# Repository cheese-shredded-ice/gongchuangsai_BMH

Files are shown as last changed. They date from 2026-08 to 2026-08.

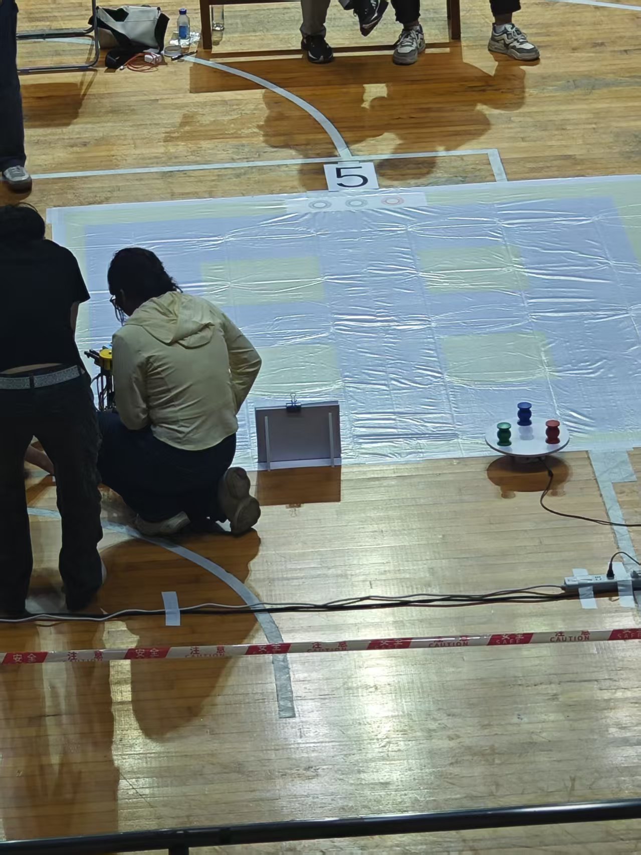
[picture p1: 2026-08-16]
图片/现场地图.jpg

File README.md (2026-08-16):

    

# 2026 年广东省工创大赛 · 智能物流搬运机器人 资料库

本仓库收录「智能物流搬运」赛项（MBH 项目）的完整参赛资料，涵盖 **结构设计、电控程序、视觉程序、任务命题文档、现场比赛经验** 五大板块。

> 项目主控：STM32F407（底层运动控制）＋ 地瓜派RDK X5（视觉识别），麦轮底盘 + 舵机机械臂 + CAN 总线电机。

> 本工程基于 [gcs-gold-medal](https://github.com/yuanxiexie531-glitch/gcs-gold-medal) 开源项目。

---

## 一、仓库结构总览

```
gongchuangsai_BMH/
├── 结构件/                  # 机械结构原始设计文件（CATIA / SolidWorks）
├── 打印部件/                # 3D 打印件模型（STP / STEP / SLDPRT / 3mf）
├── 电控程序/                # STM32F407 嵌入式工程（初赛版 / 决赛版）
├── 视觉程序/                # RDK X5 视觉主程序
│   ├── gongchuang_vision.py         # 初赛
│   └── gongchuang_vision_final.py   # 决赛
├── 图片/                    # 现场照片、地图、流程、评分表等
├── 全流程说明.md            # 系统架构、通信协议、完整任务流程
├── 2026年广东省工创大赛-设计文档MBH.docx
├── 说明文档byph.docx
├── 打印件摆盘.3mf
└── Drawingmoban.CATDrawing
```

---

## 二、结构设计

### 2.1 结构件（原始设计文件）

位于 [`结构件/`](./结构件/)：

| 文件 | 说明 |
| --- | --- |
| `zhua.CATPart` | 机械夹爪三维模型 |
| `四爪夹爪环形.SLDPRT` | 四爪夹爪（环形） |
| `Drawingmoban.CATDrawing` | CATIA 工程图模板 |

### 2.2 打印部件（3D 打印模型）

位于 [`打印部件/`](./打印部件/)，共 100+ 个零件，按功能大致分为：

- **夹爪类**：`四爪夹爪 4mm`、`2mm勾爪`、`30mm圆勾爪`、`圆勾爪`、`齿轮20x1.25 左/右爪`、`手爪固定板`、`手爪舵机固定架`、`gudinggouzhua` 等
- **平台/置物类**：`置物盘2A垫高`、`置物盘3A`、`置物盘3AHIGH`、`配重平台`、`配重盒底板`、`平台垫块`、`平台垫块支撑`
- **固定/连接类**：`固定基准板3A 4mm`、`锁紧固定板3A 4mm`、`底板3A 4mm`、`底板连接件1/2/3`、`直线导轨转接板`、`升降台固定板/转接板` 等
- **传动类**：`圆柱齿轮20×2`、`齿条模数2x20 40齿`、`齿轮20x1.25 舵机法兰盘`、`锁紧固定板带圆弧齿`
- **摄像头/传感类**：`二维码摄像头固定板C`、`向下摄像头平台`、`向下摄像头平台ov5647 3A`、`摄像头平台`、`串口屏固定板`
- **电机类**：`35电机平台`、`42步进电机支架`、`平推电机固定板35电机`、`平推转线板3.1`
- **其他**：`红物块`（比赛物块模型）、`轮胎垫片`、`舵机固定小板` 等

> 打印摆盘见 [`打印件摆盘.3mf`](./打印件摆盘.3mf)。

---

## 三、电控程序

位于 [`电控程序/`](./电控程序/)，为 STM32F407（Keil MDK）工程，含 **初赛版** 与 **决赛版** 两个版本：

| 版本 | 路径 | 说明 |
| --- | --- | --- |
| 初赛版 | [`电控程序/BMH-初赛/`](./电控程序/BMH-初赛/) | 完整工程，含全部功能模块 |
| 决赛版 | [`电控程序/BMH-决赛/`](./电控程序/BMH-决赛/) | 决赛迭代版本 |

### 核心代码模块

| 模块 | 路径 | 功能 |
| --- | --- | --- |
| `USER` | `main.c` / `car.c` / `car.h` | 主程序、整车运动控制（麦轮、走线） |
| `USER` | `cmd_parser.c/h` | 命令解析 |
| `USER` | `exti.c/h` | 外部按键中断 |
| `Hardware` | `PWM.c/h`、`servo.c/h` | 舵机 PWM 控制 |
| `Hardware` | `pid.c/h` | PID 控制 |
| `Hardware` | `swith.c/h` | 限位开关 |
| `can_ZDT` | `Emm_V5`、`can`、`circle_pid`、`yyb_move`、`fifo`、`board` | CAN 总线电机控制、环形运动、搬运移动 |
| `imu` | `imu.c`、`wit_c_sdk.c`、`timer.c`、`REG.h` | WHT101 惯性测量单元（USART2） |
| `SYSTEM` | `Serial`、`usart`、`delay`、`sys` | 串口、延时、系统基础 |
| `OLED` / `LED` | `OLED.c`、`time_OLED.c`、`LED.c`、`light.c` | 显示与指示灯 |
| `lanya` | `hmi.c`、`usart5.c` | 蓝牙 / HMI 串口屏通信 |
| `ckp` | `uart6_ckp.c/h` | 串口屏 |
| `CORE` / `FWLIB` | CMSIS + STM32F4 标准外设库 | 内核与底层驱动 |

### 调试工具

- [`CMSIS-DAP/`](./电控程序/BMH-初赛/CMSIS-DAP/)：仿真器固件（X893 版 / 官方原版）、电路原理图、WIN7 驱动、DIY 教程。

---

## 四、视觉程序

视觉端跑在 **地瓜派RDK X5** 上。源码已收录：

| 版本 | 文件 | 说明 |
| ---- | --- | --- |
| 初赛 | [`视觉程序/gongchuang_vision.py`](./视觉程序/gongchuang_vision.py) | 二维码、转盘物块、色环、码垛 |
| 决赛 | [`视觉程序/gongchuang_vision_final.py`](./视觉程序/gongchuang_vision_final.py) | 初赛能力 + 固定物料区三工位 + 成品区 Code128 转盘 |

STM32 通过 UART 下发单字节任务码，RDK X5 完成识别后按同一帧格式回传坐标、颜色或任务码。颜色约定：`1` 红、`2` 绿、`3` 蓝。决赛成品区条码 `1/2/3` 是独立编号，不走颜色映射。

### 4.1 运行环境

| 项目 | 说明 |
| --- | --- |
| 板卡 | 地瓜派RDK X5 |
| 系统 | Ubuntu / Linux（V4L2） |
| 语言 | Python 3 |
| 依赖 | `opencv-python`、`numpy`、`pyserial`、`pyzbar` |
| 串口 | `/dev/ttyUSB0`，9600 8N1 |
| 下摄像头 | `/dev/video0`，扫任务二维码 |
| 上摄像头 | `/dev/video2`，物块、色环、码垛、物料区和成品区条码  |
| OpenCV | 打开优化，8 线程 |

定标时上摄像头按 MJPEG、30 FPS、双缓冲协商分辨率。物块/色环粗定标用 `640×480`，色环精细定标切到 `1920×1080`。决赛里 `/dev/video2` 由 `ensure_video2_camera()` 统一复用，避免重复打开。

板端启动：

```bash
python3 gongchuang_vision.py          # 初赛
python3 gongchuang_vision_final.py    # 决赛
```

程序起来后先发 `987654321`，表示视觉端就绪，然后循环等 STM32 指令。

### 4.2 通信协议

收发都是：

```
0xFF + 9 字节 ASCII + 0xFE
```

不足 9 字节的数据后面补 `0x00`。STM32 发单字符任务码，视觉端回 9 字节结果。常见回传：

| 内容 | 格式 | 含义 |
| --- | --- | --- |
| 任务码 | `132+3120` 一类 7 位码再补齐 | 二维码识别结果 |
| 物块/色环坐标 | `XXXXYYYYC` | X、Y 各 4 位，C 为颜色 |
| 转盘 / 物料 / 条码夹取顺序 | `ABC456789` | 三个工位相对位置 |
| 就绪 / 确认 | `987654321` | 上电就绪，或颜色/条码确认稳定 |
| 超时 / 失败 | `000000004` | 本次识别失败 |

更细的阶段约定见 [`全流程说明.md`](./全流程说明.md) 第三、四、五章。

### 4.3 STM32 任务码

| 指令 | 函数 | 作用 |
| --- | --- | --- |
| `1` | `run_erweima()` | 下摄像头扫 7 位任务码，连续 3 帧一致后回传 |
| `2` | `run_wukuaiyuanxin_1()` | 第一圈转盘，定第一个物块圆心和颜色 |
| `a` | `run_wukuaiyuanxin_1()` | 第二圈转盘，同样先定第一个物块 |
| `3` | `LOOP1()` | 第一圈转盘转起来后，算三个物块抓取顺序 |
| `4` | `LOOP2()` | 第二圈转盘，按任务码后三位再算一遍顺序 |
| `5` / `6` | `run_wukuaiyuanxin_xuanzequyu()` | 第一圈抓完第 1、2 个后，确认下一个物块到了 |
| `b` / `c` | `run_wukuaiyuanxin_xuanzequyu()` | 第二圈同样确认后两个物块 |
| `7` | `run_sehuanyuanxin2()` | 色环第一次粗定标，`640×480` |
| `8` | `run_sehuanyuanxin2_centered()` | 色环精细定标：半分辨率粗检 + 全分辨率局部精修 |
| `9` / `0` | `run_maduoyuanxin2()` | 码垛圆环定标 |
| `d` | `yunxing_tiaoxingma_dingbiao()` | **决赛** 成品区 Code128 首次定标，回 `XXXXYYYYC` |
| `e` | `yunxing_tiaoxingma_zhuanpan()` | **决赛** 等条码变化，判向后回三次夹取位置 |
| `f` / `g` | `yunxing_tiaoxingma_xuanzequyu()` | **决赛** 确认条码 `2`、`3` 已到夹取位 |
| `h` | `run_maduoyuanxin2()` | **决赛** 固定物料区定标 |
| `i` | `yunxing_sangeyuanxin_shibie_q123()` | **决赛** 识别 Q1/Q2/Q3，按当前轮任务码回夹取顺序 |
| `r` | `restart_program()` | 关串口，20 秒后重启视觉程序 |
| `end` | 退出主循环 | 本轮任务结束 |

初赛里 `d` 只回 `000000000`，直线纠偏没启用。决赛把 `d/e/f/g` 改成成品区条码流程，`h/i` 是固定物料区。

### 4.4 识别思路

- **二维码**：`/dev/video0` 转灰度，`pyzbar` 解码，连续 3 帧相同才认。
- **转盘物块**：Hough 圆 + HSV 红绿蓝面积。红用两段色相。位置和颜色都稳定后才回传。
- **三个物块颜色**：先看左下 A1、右下 A2，A3 用排除法补出来，再对照任务码算抓取顺序。
- **色环粗定标**：全图找圆，限制在画面中部有效区，颜色和位置累计稳定后发送。
- **色环精定标**：先在中心合法区内半分辨率粗找，再切回 `1920×1080` 局部精修圆心。
- **码垛 / 物料区定标**：圆环更小，半径大约 `20~27`。
- **固定物料区（决赛 `h/i`）**：Q1/Q2/Q3 三个固定工位只看颜色。任务 `i` 第一轮对照二维码 `A1/A2/A3`，第二轮对照 `A4/A5/A6`，回 `ABC456789`。
- **成品区 Code128（决赛 `d/e/f/g`）**：`pyzbar` 只解 Code128。`d` 记下当前条码和圆心；`e` 等条码变化后，按左下/右下/上方三个位置判向，目标顺序固定为 `1→2→3`；`f/g` 再确认后两个条码到了。

上摄像头在 RDK X5 上通常只能占一路。决赛用 `ensure_video2_camera()` 共用 `/dev/video2`，避免重复打开失败。

### 4.5 依赖安装

```bash
sudo apt update
sudo apt install -y python3-opencv python3-numpy python3-serial libzbar0
pip3 install pyzbar
```

串口和摄像头权限不够时：

```bash
sudo usermod -aG dialout,video $USER
```

重新登录后再跑。

---

## 五、任务命题文档

| 文件 | 说明 |
| --- | --- |
| [`2026年广东省工创大赛-设计文档MBH.docx`](./2026年广东省工创大赛-设计文档MBH.docx) | 赛项设计文档 / 命题相关材料 |
| [`说明文档byph.docx`](./说明文档byph.docx) | 完整任务流程、通信协议、成功/失败处理汇总 |
| [`全流程说明.md`](./全流程说明.md) | 项目说明文档 |

---

## 六、现场比赛经验

现场照片与资料位于 [`图片/`](./图片/)：

| 文件 | 内容 |
| --- | --- |
| `现场.jpg` | 比赛现场全景 |
| `现场地图.jpg` | 场地地图 |
| `现场流程.jpg` | 比赛流程 |
| `评分表.jpg` | 评分标准 |
| `acsll码表.png` | ASCII 码表（调试参考） |
| `现场葫芦五兄弟.jpg`、`罪恶二维码板.jpg`、`自断一臂.jpg` | 现场记录（含场地道具、二维码板等） |

比赛关键经验与踩坑点集中在 [`全流程说明.md`](./全流程说明.md)：

- **系统架构**：STM32 管 CAN、PID、麦轮和舵机；RDK X5 管 OpenCV / pyzbar 识别，两边走 UART
- **通信协议**：`0xFF + 9 字节 ASCII + 0xFE`，单字节命令触发视觉任务
- **完整任务流程**：扫码取任务 → 圆台取料 → 穿越 1700mm 通道 → 色环放置/取回 → 返回，共 9 个阶段
- **失败处理**：视觉未识别、颜色不匹配、超时等场景的应对策略
- **注意事项**：`jixie_reset()` 末尾 `while(1){}` 会导致第二轮不运行等已知问题

---

## 七、快速导航

| 想了解什么 | 去看 |
| --- | --- |
| 系统架构与通信协议 | [`全流程说明.md`](./全流程说明.md) 第一、三章 |
| 完整任务流程（9 阶段） | [`全流程说明.md`](./全流程说明.md) 第四、六章 |
| 初赛视觉主程序 | [`视觉程序/gongchuang_vision.py`](./视觉程序/gongchuang_vision.py) |
| 决赛视觉主程序 | [`视觉程序/gongchuang_vision_final.py`](./视觉程序/gongchuang_vision_final.py) |
| 底层运动控制代码 | [`电控程序/BMH-决赛/USER/`](./电控程序/BMH-决赛/USER/) |
| 机械结构三维模型 | [`结构件/`](./结构件/) 与 [`打印部件/`](./打印部件/) |
| 现场照片与评分标准 | [`图片/`](./图片/) |

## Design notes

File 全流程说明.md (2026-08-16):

# 智能物流机器人 全流程说明文档

---

## 一、系统架构

```
┌──────────────┐       UART1 9600bps        ┌──────────────┐
│   STM32F407  │◄──────────────────────────►│   RDK X5     │
│   (底层控制)  │   0xFF + 9字节ASCII + 0xFE  │   (视觉识别)  │
│              │   单字节命令                  │              │
│  ● CAN总线   │                              │  ● OpenCV    │
│  ● PID控制   │                              │  ● pyzbar    │
│  ● 麦轮运动  │                              │  ● 串口通信   │
│  ● 舵机控制  │                              │              │
└──────────────┘                              └──────────────┘
```

**数据帧格式：**  
- STM32 → RDK X5：1字节 ASCII 命令  
- RDK X5 → STM32：`0xFF` + 9字节 ASCII 数据 + `0xFE`

视觉主程序：[`视觉程序/gongchuang_vision.py`](./视觉程序/gongchuang_vision.py)  
下摄像头 `/dev/video0` 扫码，上摄像头 `/dev/video2` 做物块 / 色环 / 码垛定标，串口 `/dev/ttyUSB0`。

---

## 二、当前版本说明

| 文件 | 说明 |
|---|---|
| `电控程序/BMH-初赛` / `电控程序/BMH-决赛` | STM32 工程。无视觉版任务码可硬编码，跳过视觉通信，只跑一轮 |
| [`视觉程序/gongchuang_vision.py`](./视觉程序/gongchuang_vision.py) | RDK X5 视觉主程序，含完整通信协议和任务分发 |

> 被注释掉的 `wait_send_shumeipai()` 等代码，在下方表格中用 **[注释]** 标记，表示完整视觉版才会执行。

---

## 三、完整通信协议表

| STM32 发送 | 触发时机 | RDK X5 收到后执行 | RDK X5 发回数据 | STM32 收到后操作 |
|:---:|---|---|---|---|
| `0x31` | **[注释]** 扫码阶段 | `run_erweima()` 打开 `/dev/video0`，pyzbar 识别二维码，连续 3 帧相同确认 | `"123+3210"` → 7 位任务码再补齐 | 解析 task[0..5] |
| `0x32` | **[注释]** 圆台物块定标 | `run_wukuaiyuanxin_1()` HoughCircle + HSV，位置稳定 30 帧 + 颜色置信度≥70% | `"095505191"` → XXXX YYYY C R | 解析像素坐标+颜色，`C_1=颜色` |
| `0x33` | **[注释]** 转盘排序(第一圈) | `LOOP1()` → 等转盘转 → `run_wukuaiyuanxin_A()` 快扫 3 位置颜色 → 判断旋转方向 → 匹配任务码前三位 | `"312456789"` → INDEX INDEX1 INDEX2 | 解析为 ypcode[0..2] |
| `0x34` | **[注释]** 转盘排序(第二圈) | `LOOP2()`，逻辑同第一圈，对照任务码后三位 | `"312456789"` | 解析为第二圈 ypcode |
| `0x35` | **[注释]** 第一圈确认第2物块 | `run_wukuaiyuanxin_xuanzequyu()` 验证指定区域颜色是否 = 任务码 | `"987654321"` | 收到"98" → 确认通过，执行抓取 |
| `0x36` | **[注释]** 第一圈确认第3物块 | 同上，验证第3个位置的颜色 | `"987654321"` | 同上 |
| `0x37` | **[注释]** 色环粗定标 | `run_sehuanyuanxin2()` 640×480, r=35~38, 位置+颜色稳定性确认 | `"095505191"` → XXXX YYYY C | 像素坐标 ×1.18 → 实际距离 |
| `0x64` | **[注释]** 角度校正 | 当前视觉端未跑 `detect_boundary_line()`，直接回全零 | `"000000000"` | 现场按 0° 处理 |
| `0x38` | **[注释]** 色环精定标 | `run_sehuanyuanxin2_centered()` 1920×1080，半分辨率粗检 + 全分辨率局部精修 | `"095505191"` | 像素坐标 ×0.29 → 细调距离 |
| `0x39` | **[注释]** 码垛定标 | `run_maduoyuanxin2()` 640×480, r=20~27 | `"095505191"` | 码垛位置定位 |
| `0x30` | **[注释]** 码垛精定标 | 同上 | `"095505191"` | 码垛精确定位 |
| `0x61` | **[注释]** 第二圈物块定标 | `run_wukuaiyuanxin_1()` 结果存 C_1_loop2 | 同上 0x32 | 第二圈坐标 |
| `0x62` | **[注释]** 第二圈确认第2物块 | 同 0x35 逻辑 | `"987654321"` | 确认 |
| `0x63` | **[注释]** 第二圈确认第3物块 | 同 0x36 逻辑 | `"987654321"` | 确认 |
| `0x72` | 重启视觉 | `restart_program()` 关串口，20 秒后重启 | — | — |
| (初始化) | 程序启动时 | `send_data("987654321")` 握手信号 | — | STM32 可据此判断视觉端就绪 |

颜色约定：`1` 红、`2` 绿、`3` 蓝。识别失败超时回 `"000000004"`。

---

## 四、完整任务流程

> 📌 当前部分电控工程仍是**无视觉简化版**，任务码硬编码为 `红=1, 绿=2, 蓝=3`，视觉通信大部分被注释。下方列出完整版流程（注释代码 + 当前执行代码结合）。视觉端本身已按完整协议实现。

---

### 阶段0：系统初始化

| 步骤 | 操作 | 说明 |
|:---:|---|---|
| 0.1 | `delay_init(168)` | 168MHz系统时钟 |
| 0.2 | `board_init()` | CAN总线 500Kbps 初始化 |
| 0.3 | `LED_Init()` | LED指示灯 |
| 0.4 | `OLED_Init()` | OLED屏幕 |
| 0.5 | `Timer6_Init()` | delay_ms1 定时器 |
| 0.6 | `PWM_Init()` | 舵机PWM (TIM3, 20ms周期) |
| 0.7 | `uart5_init(9600)` | 调试串口 |
| 0.8 | `uart6_init(9600)` | HMI串口屏 |
| 0.9 | `Serial_Init()` | UART1 (RDK X5 通信) |
| 0.10 | `Swith_Init()` | 限位开关 |
| 0.11 | `imu_init()` | WHT101 IMU (USART2) |
| 0.12 | `PIDInit()` | PID定时器 (TIM4, 50ms周期) |
| 0.13 | `Key_EXTI_Init()` | 外部按键中断 |
| 0.14 | `dianji_move_flag = 1` | 使能电机 |

---

### 阶段0.5：等待就绪

| 步骤 | 动作 | STM32 发送 | RDK X5 发回 | 成功 | 失败处理 |
|:---:|---|:---:|---|---|---|
| — | OLED显示 `"OK-noeye"`，LED闪烁等待 | — | — | 用户按下限位开关 | 一直等待 |
| — | `WHT101_ANGLEZCali()` | — | — | IMU零位校准完成 | — |
| — | `TIM_SetCompare1(TIM3, 300)` | — | — | 补光灯打开 | — |

---

### 阶段1：二维码扫描 & 任务获取

#### 完整版流程（被注释）
| 步骤 | 动作 | STM32 发送 | RDK X5 执行 | RDK X5 发回 | 成功 | 失败 |
|:---:|---|:---:|---|---|---|---|
| 1.1 | `car_move2(150,0,150,150)` 右移150mm | — | — | — | — | — |
| 1.2 | `car_move1(0,-530,150,200)` 后退530mm | — | — | — | — | — |
| 1.3 | 发送扫码命令 | `0x31` | `run_erweima()` | `"123+3210"` | 解析 task[0..5] 并串口屏显示 | RDK X5 发 `"二维码数据错误"`，无处理 |
| 1.4 | 存储平台归零 | — | — | — | `set_wukuaipingtai_Angle(20, 300)` | — |

#### 当前简化版（实际执行）
```
task[0]=1  task[1]=2  task[2]=3       ← 硬编码，无通信
task[3]=1  task[4]=2  task[5]=3       ← 硬编码，无通信
```

---

### 阶段2：圆台取料（第一轮3个物块）

| 步骤 | 动作 | STM32 发送 | RDK X5 执行 | RDK X5 发回 | 成功 | 失败处理 |
|:---:|---|:---:|---|---|---|---|
| 2.1 | `set_zhuashou_Angle(25, 300)` | — | — | — | 爪子张开 | — |
| 2.2 | `car_move1(0, -910, 150, 200)` → 后退910mm | — | — | — | 退到观察位 | — |
| 2.3 | `move_all(85, ..., 250, 10)` → 升臂，云台转250° | — | — | — | 对准转盘 | — |
| 2.4 | **[注释]** 发物块定标 | `0x32` | `run_wukuaiyuanxin_1()` | `"XXXXYYYYCR"` | 粗定位完成 | `Serial_RxPacket[8]==0x34`→重发 |
| 2.5 | `car_move2(-30, 0, 100, 100)` → 左移30mm微调 | — | — | — | — | — |
| 2.6 | **[注释]** 发转盘排序 | `0x33` | `LOOP1()` | `"312456789"` | ypcode=[3,1,2] | 超时等20s |
| 2.7 | **当前简化版**: ypcode[0]=1, ypcode[1]=2, ypcode[2]=3 | — | — | — | 硬编码 | — |
| 2.8 | `delay_ms1(1000)` 等待1秒 | — | — | — | — | — |

---

#### 2A：抓取第1个物块（ypcode[0]=1 → 红色区）

| 步骤 | 动作 | 说明 |
|:---:|---|---|
| 2A.1 | `yuantai_na(1)` → 爪子张开25° → 伸臂-20mm → 爪子闭合1.5° → 收臂回72° → 爪子张开25° | 完整抓取动作 |
| 2A.2 | `move_all(0, ..., 72, 13)` → 收臂归位 | 回到安全位 |
| 2A.3 | `set_wukuaipingtai_Angle(144, 300)` → 物块存储平台转144° | 第1个存储工位 |

#### 2B：抓取第2个物块（ypcode[1]=2 → 绿色区）

| 步骤 | 动作 | STM32 发送 | RDK X5 执行 | RDK X5 发回 | 成功 | 失败 |
|:---:|---|:---:|---|---|---|---|
| 2B.1 | `yuantai_na1(2)` → 爪子张开25° → 伸臂对准绿位(235°) | — | — | — | 对准完成 | — |
| 2B.2 | **[注释]** 颜色确认 | `0x35` | `run_wukuaiyuanxin_xuanzequyu()` | `"987654321"` | 确认颜色匹配 | 重发等待 |
| 2B.3 | `yuantai_na2(2)` → 抓取闭合(1.5°) → 收回 | — | — | — | 绿色物块抓取完成 | — |
| 2B.4 | `set_wukuaipingtai_Angle(258, 300)` → 平台转258° | — | — | — | 第2个存储工位 | — |

#### 2C：抓取第3个物块（ypcode[2]=3 → 蓝色区）

| 步骤 | 动作 | STM32 发送 | RDK X5 执行 | RDK X5 发回 |
|:---:|---|:---:|---|---|
| 2C.1 | `yuantai_na1(3)` → 对准蓝位(276°) | — | — | — |
| 2C.2 | **[注释]** 颜色确认 | `0x36` | 验证第3位置 | `"987654321"` |
| 2C.3 | `yuantai_na2(3)` → 抓取 | — | — | — |

#### 取料完成

| 步骤 | 动作 |
|:---:|---|
| 2D.1 | `TIM_SetCompare1(TIM3, 0)` → 关补光灯 |
| 2D.2 | `move_all1(0,...,72,13)` → 臂归位 |
| 2D.3 | `set_zhuashou_Angle(30, 200)` → 爪子半开 |
| 2D.4 | `set_wukuaipingtai_Angle(20, 300)` → 平台归零 |

---

### 阶段3：穿越1700mm通道

| 步骤 | 动作 | PID参数 | 说明 |
|:---:|---|:---:|---|
| 3.1 | `PID_move(-30, 0, 0, 400, 0, 1)` | kp=3.3, kd=1.8, max=30 | 后退靠墙 |
| 3.2 | `delay_ms1(200)` | — | 等待200ms |
| 3.3 | `car_move1(0, 400, 150, 200)` | — | 前进400mm |
| 3.4 | `PID_move(0, 0, 0, 1000, 90, 0)` | kp=2.0, kd=0.8 | **原地旋转90°** (对准通道) |
| 3.5 | `PID_move(0, 0, 0, 1000, 90, 3)` | kp=2.0, ki=0.05, kd=0.4 | 微调确认90° |
| 3.6 | `car_move1(0, -1700, 150, 250)` | — | **穿越1700mm通道** |
| 3.7 | `PID_move(0, 0, 0, 1000, -180, 0)` | kp=2.0, kd=0.8 | **原地旋转180°** (面向色环) |
| 3.8 | `PID_move(0, 0, 0, 1000, -180, 3)` | kp=2.0, ki=0.05, kd=0.4 | 微调确认180° |

---

### 阶段4：色环放置（第一轮3个物块）

#### 视觉定位（完整版，当前被注释）

| 步骤 | STM32 发送 | RDK X5 执行 | 发回 | STM32 操作 | 失败处理 |
|:---:|:---:|---|---|---|---|
| 粗定标 | `0x37` | `run_sehuanyuanxin2()` | `"XXXXYYYYC"` | `direct = 像素差×1.18` | 未识别→重发 |
| 角度校正 | `0x64` | 当前直接回 `"000000000"` | `"000000000"` | 现场按 0° 处理 | 未启用直线检测 |
| 精定标 | `0x38` | `run_sehuanyuanxin2_centered()` | `"XXXXYYYYC"` | `direct = 像素差×0.29` | 未识别→不移动 |

#### 当前简化版（无视觉）→ 直接角度校准后放置

| 步骤 | 动作 | 说明 |
|:---:|---|---|
| 4.1 | `PID_move(0, 0, 0, 1000, -180, 4)` | kp=2.0, ki=0.07, kd=0.4 角度校准 |
| 4.2 | `set_zhuashou_Angle(25.5, 200)` | 爪子半开 |
| 4.3 | `move_all(0,...,35,...,72,13)` | 臂伸出对准色环 |

#### 4A：放置第1个物块（task[0]=1 → 红色环）

| 步骤 | 动作 |
|:---:|---|
| 4A.1 | `set_zhuashou_Angle(1.5, 200)` → 爪子闭合抓住 |
| 4A.2 | `fangzhi(1)` → `fangzhi_red()` → 臂伸向193°（红色色环位置） |
| 4A.3 | `set_zhuashou_Angle(25, 300)` → 松开物块 |
| 4A.4 | `set_wukuaipingtai_Angle(143, 300)` → 存储平台转143° |
| 4A.5 | `shengjiang_control(0)` → 升降复位 |
| 4A.6 | `move_all(...)` → 臂收回72° |

#### 4B：放置第2个物块（task[1]=2 → 绿色环）

| 步骤 | 动作 |
|:---:|---|
| 4B.1 | `fangzhi(2)` → `fangzhi_green()` → 臂伸向247.9° |
| 4B.2 | 平台转258°，臂收回 |

#### 4C：放置第3个物块（task[2]=3 → 蓝色环）

| 步骤 | 动作 |
|:---:|---|
| 4C.1 | `fangzhi(3)` → `fangzhi_blue()` → 臂伸向300.5° |
| 4C.2 | 平台归零20°，臂归位193° |

---

### 阶段5：色环取回

| 步骤 | 动作 | 说明 |
|:---:|---|---|
| 5.1 | `na(task[0])` → `na_red()` → 伸臂到193° → 闭合1.5°抓取 → 收回72° | 取回红色位 |
| 5.2 | 平台转143° | |
| 5.3 | `na(task[1])` → `na_green()` → 伸臂247.9° → 抓取 → 收回 | 取回绿色位 |
| 5.4 | 平台转258° | |
| 5.5 | `na(task[2])` → `na_blue()` → 伸臂300.5° → 抓取 → 收回 | 取回蓝色位 |
| 5.6 | 平台归零，爪子张开25° | 复位 |

---

### 阶段6：返回圆台区

| 步骤 | 动作 | PID | 说明 |
|:---:|---|:---:|---|
| 6.1 | `PID_move(-30, 0, 0, 300, -180, 1)` | kp=3.3 | 后退 |
| 6.2 | `PID_move(0, 0, 0, 500, -180, 3)` | kp=2.0, ki=0.05 | 微调 |
| 6.3 | `car_move1(140, 820, 180, 180)` | — | 走蓝线 |
| 6.4 | `PID_move(0, 0, 0, 1000, 90, 0)` | kp=2.0 | **旋转90°** |
| 6.5 | `PID_move(0, 0, 0, 1000, 90, 3)` | 带积分 | 微调 |
| 6.6 | `car_move1(140, 760, 180, 150)` | — | 前进 |

---

### 阶段7：第二轮色环放置

> 与阶段4 完全一致（重新放置 task[0], task[1], task[2]），最终复位。

---

### 阶段8：返回圆台

| 步骤 | 动作 | 说明 |
|:---:|---|---|
| 8.1 | `PID_move(-30, 0, 0, 300, 90, 1)` | 后退 |
| 8.2 | `car_move1(140, 870, 180, 180)` | 走蓝线 |
| 8.3 | `PID_move(0, 0, 0, 1000, 0, 0)` | **旋转0°** |
| 8.4 | `PID_move(0, 0, 0, 1000, 0, 3)` | 微调 |
| 8.5 | `car_move1(140, 390, 180, 180)` | 前进 |
| 8.6 | `move_all1(40, ..., 278, 13)` | 云台转278° |
| 8.7 | `PID_move(30, 0, 0, 300, 0, 1)` | 前进靠墙 |

---

### 阶段9：jixie_reset() → 程序结束

```
while(swith_out()) { LED闪烁 }  → 等待限位开关触发
set_zhuashou_Angle(15, 300)     → 爪子半闭
move_all(0,...,72,13)           → 臂归位
set_wukuaipingtai_Angle(20,300) → 平台归零
while(1){}                       → 死循环结束
```

> ⚠️ 当前代码 `jixie_reset()` 末尾有 `while(1){}`，执行后程序在此终止，**第二轮不会运行**。

---

## 五、通信成功/失败处理汇总

| 场景 | STM32 行为 | RDK X5 行为 |
|---|---|---|
| **成功发送命令** | `wait_send_shumeipai()` 阻塞等待回复 | 收到命令 → 执行视觉任务 → `send_data()` 发回 |
| **视觉端超时未回复** | `wait_send_shumeipai()` 死等（无超时） | — |
| **视觉未识别到物体** | `RxPacket[8]==0x34` → 重发命令 | 超时 8s 后发 `"000000004"` |
| **视觉识别到物体** | 跳出循环，继续执行 | 发回坐标+颜色 |
| **颜色验证不匹配** | 不执行（当前注释） | `run_wukuaiyuanxin_xuanzequyu()` 循环等待直到匹配 |
| **颜色验证匹配** | 收到"98" → 跳出等待 | 发 `"987654321"` |
| **串口无数据** | 死等 | — |
| **程序异常** | — | 收到 `"r"` → 20s 后重启 |

---

## 六、全流程时空图

```
初始化 ─→ 等开关 ─→ IMU归零 ─→ 补光灯开
  │
  ├─①─ 扫码位移动(150, -530)
  │    task=[1,2,3,1,2,3] ← 硬编码（无视觉版）
  │    完整版：0x31 → RDK X5 扫码回传任务码
  │
  ├─②─ 圆台取料
  │    退910mm → 升臂250° → 抓1(红) → 存144°
  │    → 抓2(绿) → 存258° → 抓3(蓝)
  │    → 关灯复位
  │
  ├─③─ 穿越通道
  │    退 → 进400 → 转90° → 直走1700mm → 转180°
  │
  ├─④─ 色环放置(第一轮)
  │    角度校准 → 放红(193°) → 放绿(248°) → 放蓝(301°)
  │    → 复位193°
  │
  ├─⑤─ 色环取回
  │    取红 → 取绿 → 取蓝 → 平台归零
  │
  ├─⑥─ 返回
  │    退 → 走蓝线820 → 转90° → 走760
  │
  ├─⑦─ 色环放置(第二轮) → 复位
  │
  ├─⑧─ 返回圆台
  │    退 → 走蓝线870 → 转0° → 走390 → 云台278° → 前进靠墙
  │
  └─⑨─ jixie_reset() → while(1){} 结束
```

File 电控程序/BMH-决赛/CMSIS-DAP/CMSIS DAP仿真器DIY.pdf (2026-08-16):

# 电子屌丝的的情怀：CMSIS DAP 仿真器

说到 ARM 开发，仿真器（准确的说应该是调试器）是必不可少的工具，开发人员可以用它进行程序的下载、 调试，在很多时候在线调试可以让程序开发更高效。市面上有很多仿真器产品，最出名的莫过于大名鼎鼎 的 Jlink。Jlink 除了可以在 MDK、IAR 等软件中得到很好支持外，官方还有很多与 Jlink 配套的工具以方 便用户使用。但是说实话，现在市场上流通的 Jlink 基本都是盗版的，至于正版的价格大家可以到 SEGGER 官网看一下，作为一名电子屌丝，反正我是被吓到了。犹记得笔者当年初学 STM32 的时候，随便 30 来块钱 就能买到一个，不过盗版毕竟是盗版，用起来还是不太稳定。
后来听说了 Jlink-OB，网上有很多爱好者 DIY 的各种版本。所谓 OB 就是 On Board，是 SEGGER 专门开发用 于把 Jlink 集成到 PCB 板卡上方便调试下载的版本，可以理解为精简版的 Jlink。当时笔者也做了一个， 基于 X893 大神的版本，带了串口。说到 X893，这是一个大神博主的名称，它的博客上有个 STM32 版块，分 享了 好多文章，网上流传的 JlinkOB 大多数都是 用的 X893 的版本。这是 原博文 地址： http://akb77.com/g/stm32/jlink-ob/
这是当时笔者 DIY 的 Jlink-OB，精简了一下，把输出电源改成了 5V，还改了引脚排列。说实话，当时对这 个仿真器是爱不释手，基本 Jlink 的功能都有，而且很稳定，还带了串口，下载、调试、串口、供电，一 个小小的 JlinkOB 全解决了，再也不用拖着一个砖头还要另外加一个 USB 转串口模块。

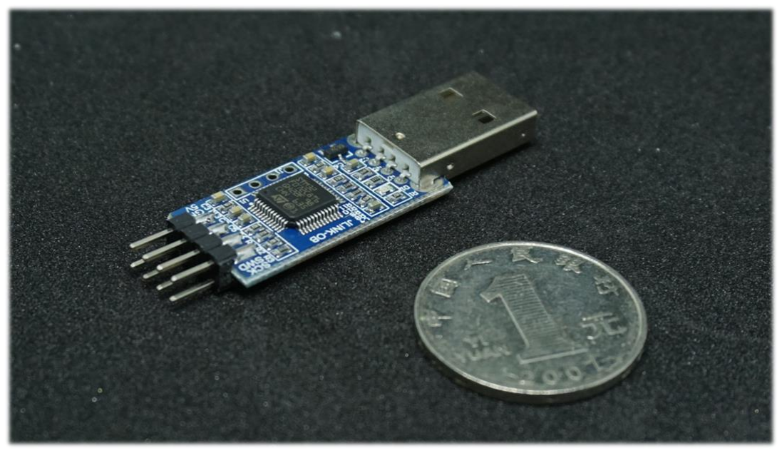
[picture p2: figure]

再后来，了解到 CMSIS DAP，可能很多朋友第一次听说这个名词。CMSIS DAP 是 ARM 官方推出的开源仿真 器，支持所有的 Cortex-A/R/M 器件，支持 JTAG/SWD 接口，在最新的固件版本中，还支持单线 SWO 接口， 可以直接在程序里把相应的数据通过 SWO 接口输出到调试窗口，起到类似串口调试的目的。DAP 主要有以 下特点：
1. 完全开源，没有版权限制，所以相应的价格会很便宜
2. 无须驱动，即插即用
3. 在新版本的 DAP 里集成了串口，除了下载调试外还能充当 USB 转串口模块，一机两用
4. 性能方面已经可以满足一般用户的需求
毕竟是开源的，经过这几年的发展，网上也有很多的版本，笔者这次用的同样也是 X893 大神的版本。不过 在它的博客里没有相应的博文介绍，我是在 Git 上面找到的，连接如下： https://github.com/x893/CMSIS-DAP。
ARM 官网的 DAP 介绍：
http://www.keil.com/pack/doc/cmsis/DAP/html/index.html。

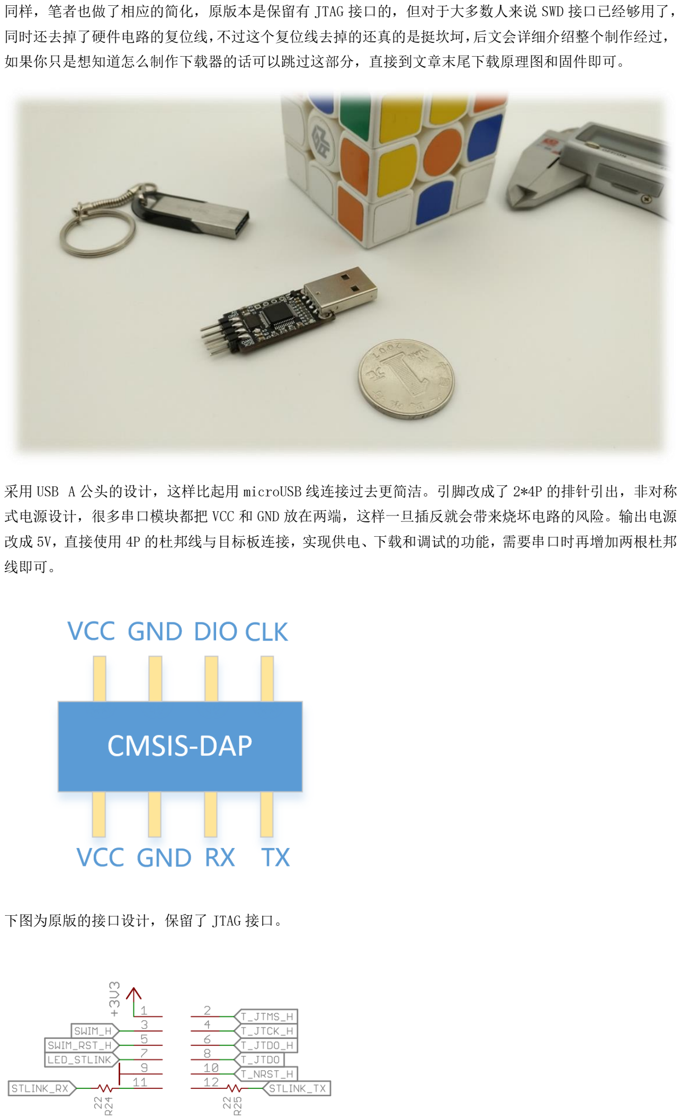
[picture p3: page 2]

同样，笔者也做了相应的简化，原版本是保留有 JTAG 接口的，但对于大多数人来说 SWD 接口已经够用了， 同时还去掉了硬件电路的复位线，不过这个复位线去掉的还真的是挺坎坷，后文会详细介绍整个制作经过， 如果你只是想知道怎么制作下载器的话可以跳过这部分，直接到文章末尾下载原理图和固件即可。

采用 USB A 公头的设计，这样比起用 microUSB 线连接过去更简洁。引脚改成了 2*4P 的排针引出，非对称 式电源设计，很多串口模块都把 VCC 和 GND 放在两端，这样一旦插反就会带来烧坏电路的风险。输出电源 改成 5V，直接使用 4P 的杜邦线与目标板连接，实现供电、下载和调试的功能，需要串口时再增加两根杜邦 线即可。

下图为原版的接口设计，保留了 JTAG 接口。

因为之前制作 JlinkOB 也是用的 X893 版本，那时候 X893 的 Jlink 也是保留了复位线，由于 Jlink 会使用 软复位，硬件复位线是可以去掉的，所以设计成了上面的接口布局，一直用着，很稳定没出现问题。所以 这次制作 CMSIS DAP 的时候去掉 JTAG 接口的同时也去掉了复位线，然后实际使用的时候发现能正常下载程 序和调试，但是就是不能在下载程序的时候复位运行。起初以为是 MDK 里面设置的问题，于是把 MDK 里面 关于下载调试的所有设置都试了一遍，还是没有复位。
在 MDK 下载选项那里有一个下载后复位和运行的选项，在接上复位线的前提下，勾选了这个选项，下载程 序发现可以正常复位，去掉勾选之后下载程序芯片没有自动复位，说明 DAP 还是接收了 MDK 相关复位指令 的。接下来的测试中发现，去掉复位线下载程序之后芯片没有复位运行，但是一点击进入调试，在调试状 态下点击运行芯片就马上执行运行了，而且退出调试之后也会复位。这说明了其实 DAP 是有软件复位的， 只是在下载结束之后只进行了硬件复位。加上之前使用 Jlink 用的软复位一直没有出现过问题，这就更加 证实了 DAP 是完全可以使用软复位的，继而省掉复位线，更加精简。 既然要实现软复位那肯定是操作某个寄存器，查阅《Cortex M3 与 M4 权威指南》，其中 Table 7.20 有着关 于复位 SCB->AIRCR 寄存器的介绍。从表格中可以看出，要想操作这个寄存器，首先得往高 16 位写入校验 字，如果是写操作则写入 0X05FA，读操作则写入 0XFA05。与复位操作有关的是 bit2 和 bit0，操作 bit0 的 话只会复位核心处理单元，片内的其他外设都不会复位，是专门设计用于调试操作的，操作 bit2 则可以实 现整个芯片的复位。那么基本思路就出来了，我们只要往地址为 0XE000ED0C 的寄存器 SCB->AIRCR 写入 0X05FA0004 即可实现我们要的复位功能。

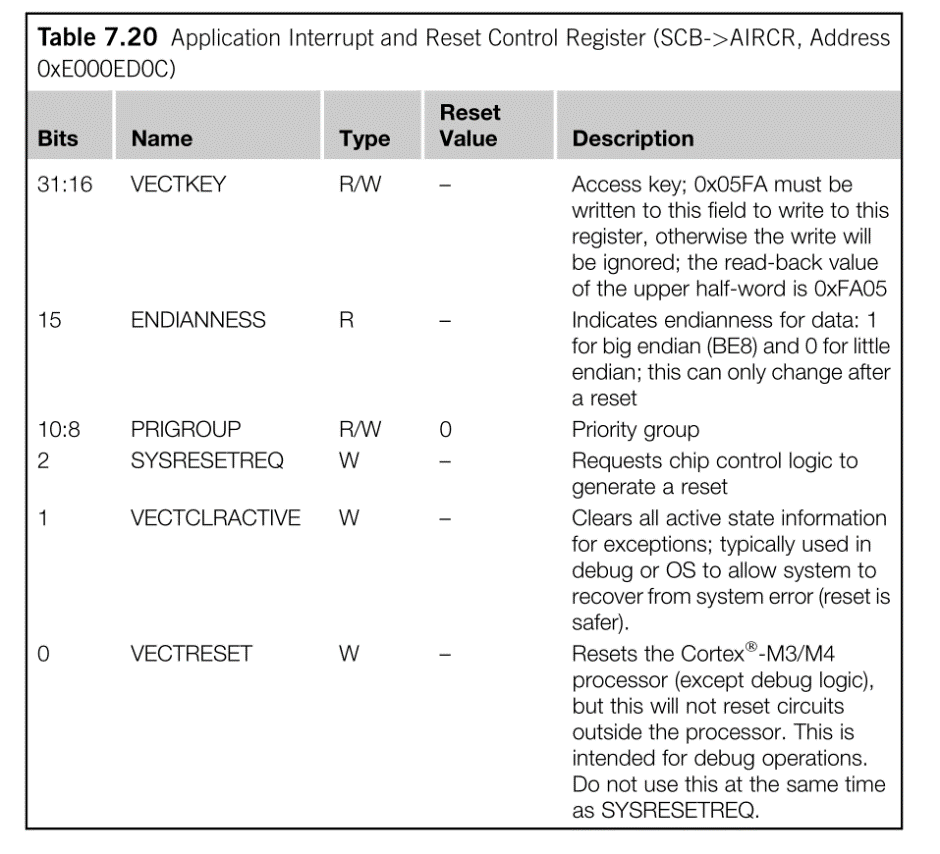
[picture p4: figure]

既然知道了要怎么操作寄存器，那么另一个问题就是要怎么通过 CMSIS DAP 去操作相关的寄存器？所谓 DAP 其实是 Debug Port 和 Access Port 的简称，外部的调试工具通过 SWD 或 JTAG 接口去访问芯片内部的 DP 和 AP 端口，通过 DP 和 AP 端口执行相应的操作。DP 端口主要是进行一些与调试相关的操作或者控制，与我们 本次的目的相关不大，所以这里不做过多介绍。而 AP 端口的作用就是可以通过它对芯片所有的寄存器进行 访问和操作。

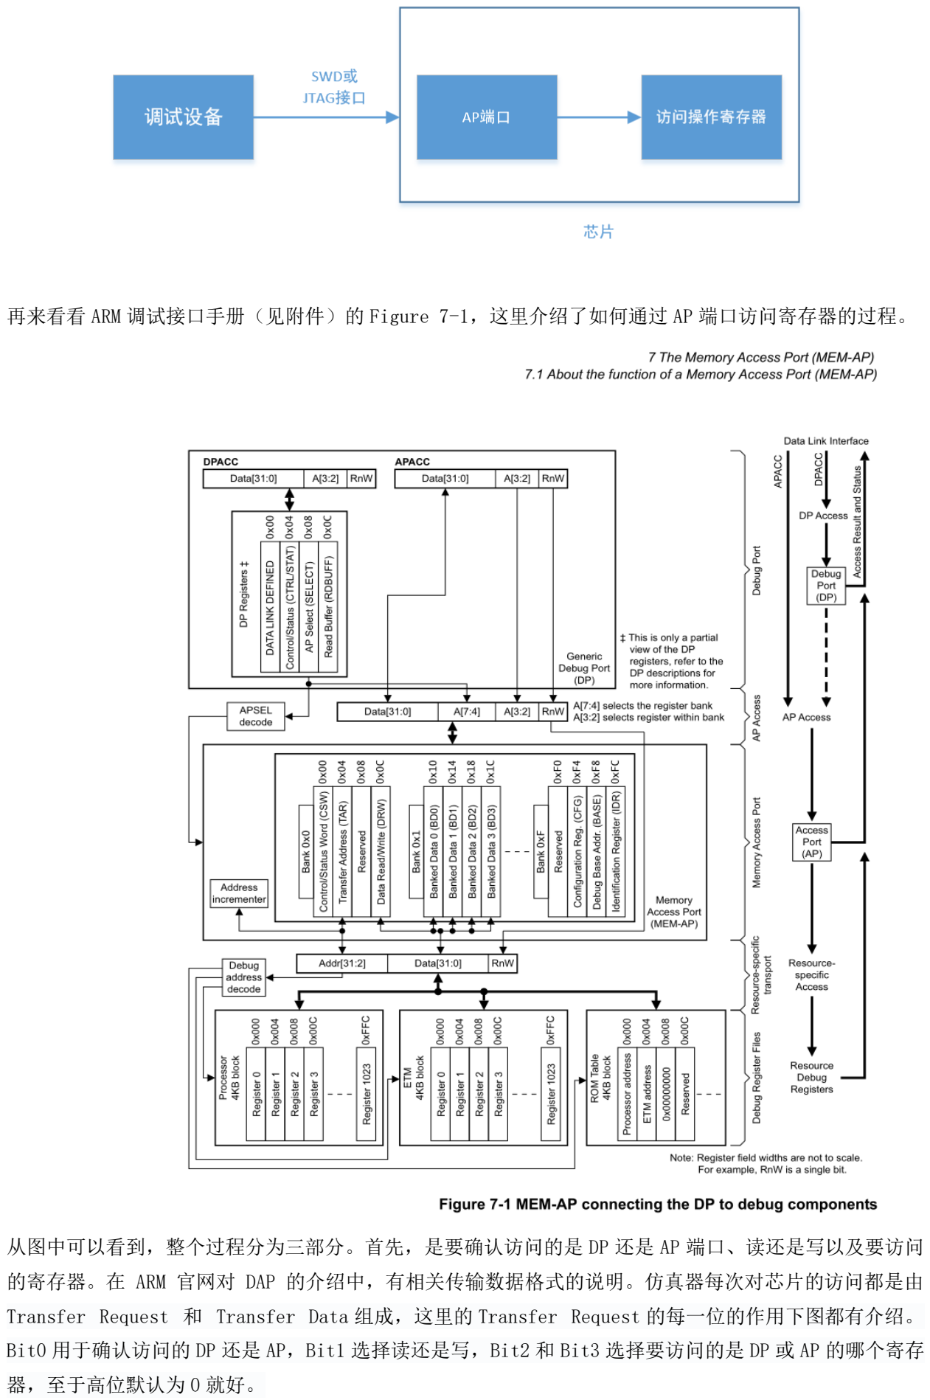
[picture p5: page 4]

再来看看 ARM 调试接口手册（见附件）的 Figure 7-1，这里介绍了如何通过 AP 端口访问寄存器的过程。

从图中可以看到，整个过程分为三部分。首先，是要确认访问的是 DP 还是 AP 端口、读还是写以及要访问 的寄存器。在 ARM 官网对 DAP 的介绍中，有相关传输数据格式的说明。仿真器每次对芯片的访问都是由 Transfer Request 和 Transfer Data 组成，这里的 Transfer Request 的每一位的作用下图都有介绍。 Bit0 用于确认访问的 DP 还是 AP，Bit1 选择读还是写，Bit2 和 Bit3 选择要访问的是 DP 或 AP 的哪个寄存 器，至于高位默认为 0 就好。

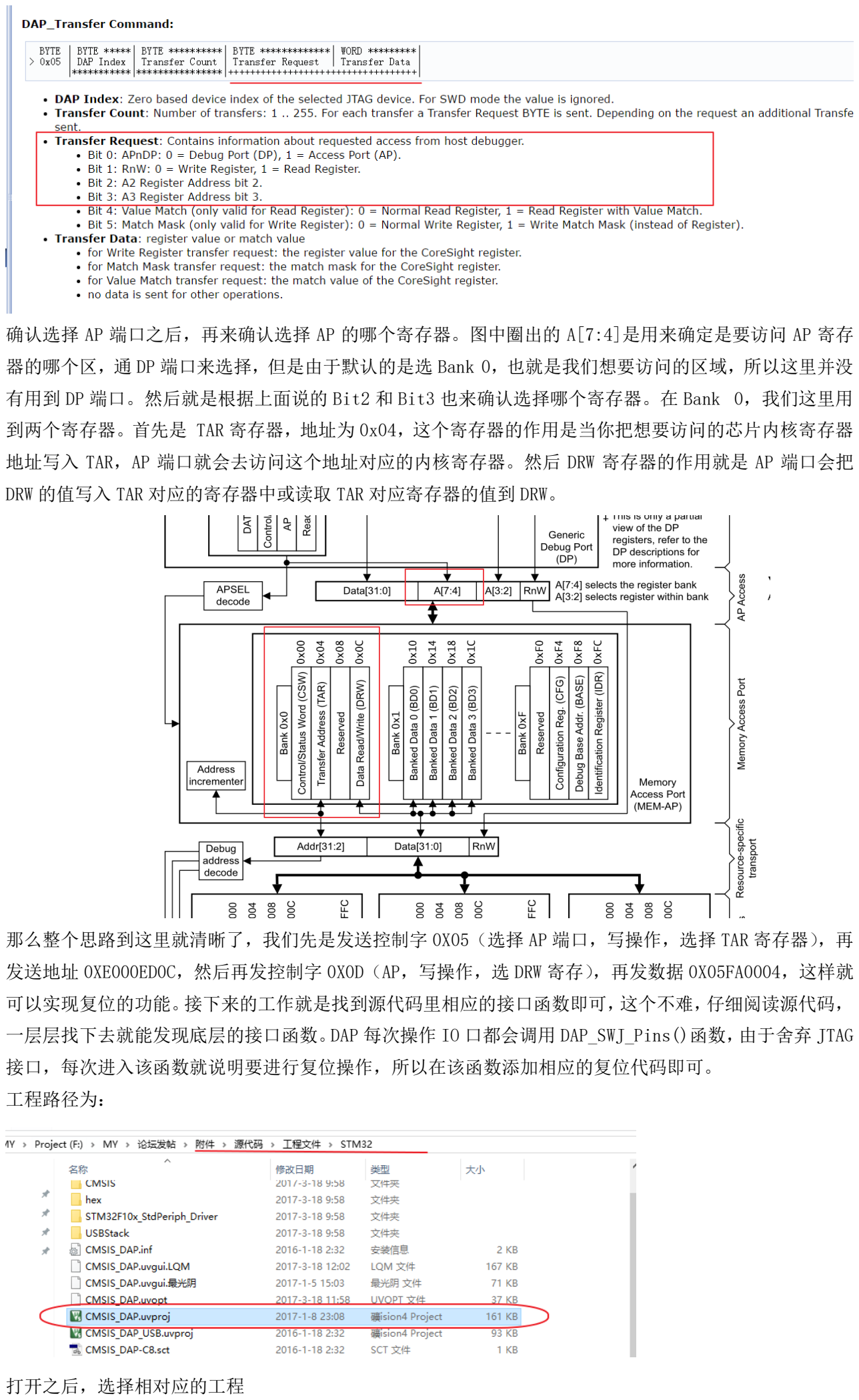
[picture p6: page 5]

确认选择 AP 端口之后，再来确认选择 AP 的哪个寄存器。图中圈出的 A[7:4]是用来确定是要访问 AP 寄存 器的哪个区，通 DP 端口来选择，但是由于默认的是选 Bank 0，也就是我们想要访问的区域，所以这里并没 有用到 DP 端口。然后就是根据上面说的 Bit2 和 Bit3 也来确认选择哪个寄存器。在 Bank 0，我们这里用 到两个寄存器。首先是 TAR 寄存器，地址为 0x04，这个寄存器的作用是当你把想要访问的芯片内核寄存器 地址写入 TAR，AP 端口就会去访问这个地址对应的内核寄存器。然后 DRW 寄存器的作用就是 AP 端口会把 DRW 的值写入 TAR 对应的寄存器中或读取 TAR 对应寄存器的值到 DRW。

那么整个思路到这里就清晰了，我们先是发送控制字 0X05（选择 AP 端口，写操作，选择 TAR 寄存器），再 发送地址 0XE000ED0C，然后再发控制字 0X0D（AP，写操作，选 DRW 寄存），再发数据 0X05FA0004，这样就 可以实现复位的功能。接下来的工作就是找到源代码里相应的接口函数即可，这个不难，仔细阅读源代码， 一层层找下去就能发现底层的接口函数。DAP 每次操作 IO 口都会调用 DAP_SWJ_Pins()函数，由于舍弃 JTAG 接口，每次进入该函数就说明要进行复位操作，所以在该函数添加相应的复位代码即可。 工程路径为：

打开之后，选择相对应的工程

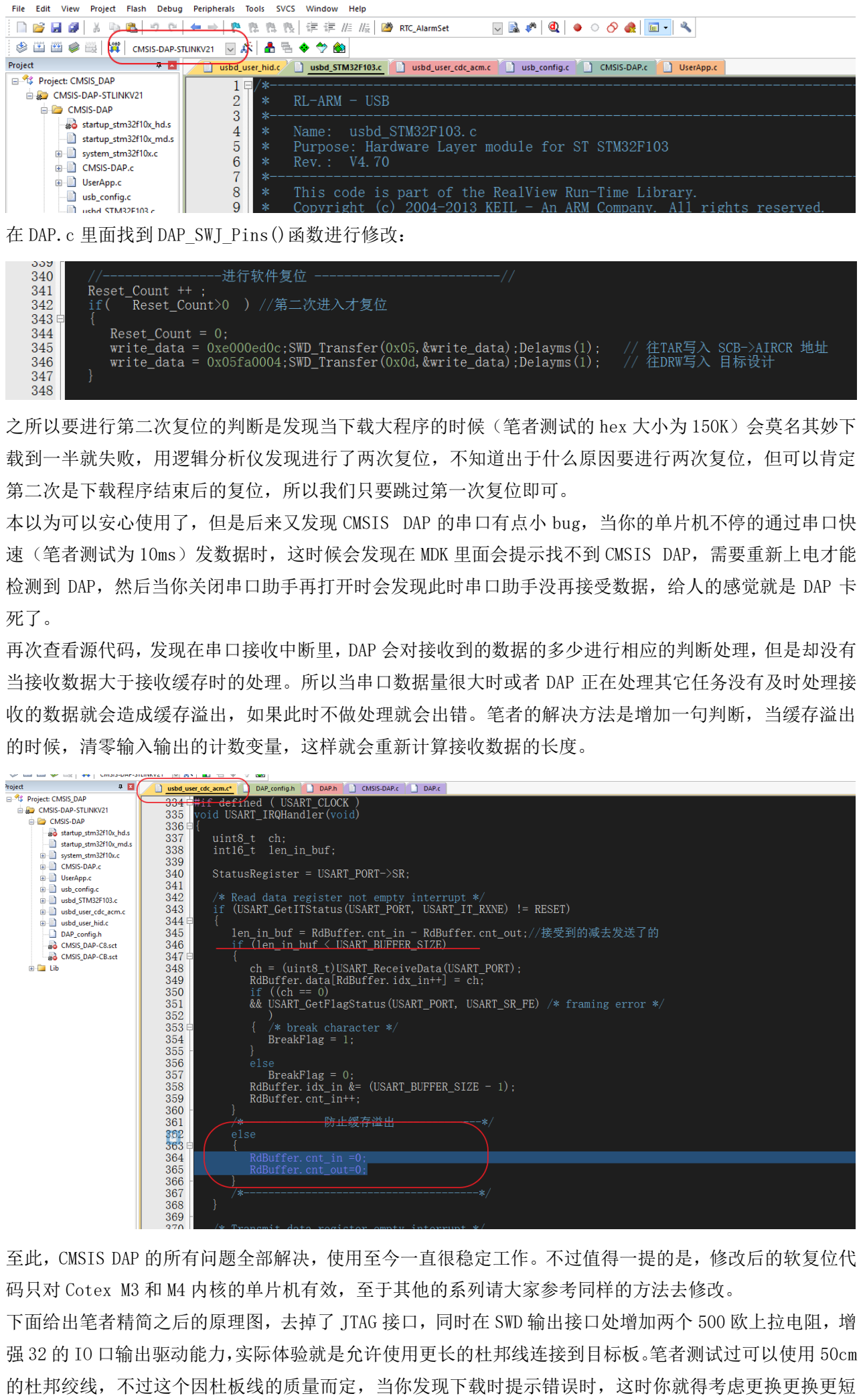
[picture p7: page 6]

在 DAP.c 里面找到 DAP_SWJ_Pins()函数进行修改：

之所以要进行第二次复位的判断是发现当下载大程序的时候（笔者测试的 hex 大小为 150K）会莫名其妙下 载到一半就失败，用逻辑分析仪发现进行了两次复位，不知道出于什么原因要进行两次复位，但可以肯定 第二次是下载程序结束后的复位，所以我们只要跳过第一次复位即可。 本以为可以安心使用了，但是后来又发现 CMSIS DAP 的串口有点小 bug，当你的单片机不停的通过串口快 速（笔者测试为 10ms）发数据时，这时候会发现在 MDK 里面会提示找不到 CMSIS DAP，需要重新上电才能 检测到 DAP，然后当你关闭串口助手再打开时会发现此时串口助手没再接受数据，给人的感觉就是 DAP 卡 死了。
再次查看源代码，发现在串口接收中断里，DAP 会对接收到的数据的多少进行相应的判断处理，但是却没有 当接收数据大于接收缓存时的处理。所以当串口数据量很大时或者 DAP 正在处理其它任务没有及时处理接 收的数据就会造成缓存溢出，如果此时不做处理就会出错。笔者的解决方法是增加一句判断，当缓存溢出 的时候，清零输入输出的计数变量，这样就会重新计算接收数据的长度。

至此，CMSIS DAP 的所有问题全部解决，使用至今一直很稳定工作。不过值得一提的是，修改后的软复位代 码只对 Cotex M3 和 M4 内核的单片机有效，至于其他的系列请大家参考同样的方法去修改。 下面给出笔者精简之后的原理图，去掉了 JTAG 接口，同时在 SWD 输出接口处增加两个 500 欧上拉电阻，增 强 32 的 IO 口输出驱动能力，实际体验就是允许使用更长的杜邦线连接到目标板。笔者测试过可以使用 50cm 的杜邦绞线，不过这个因杜板线的质量而定，当你发现下载时提示错误时，这时你就得考虑更换更换更短

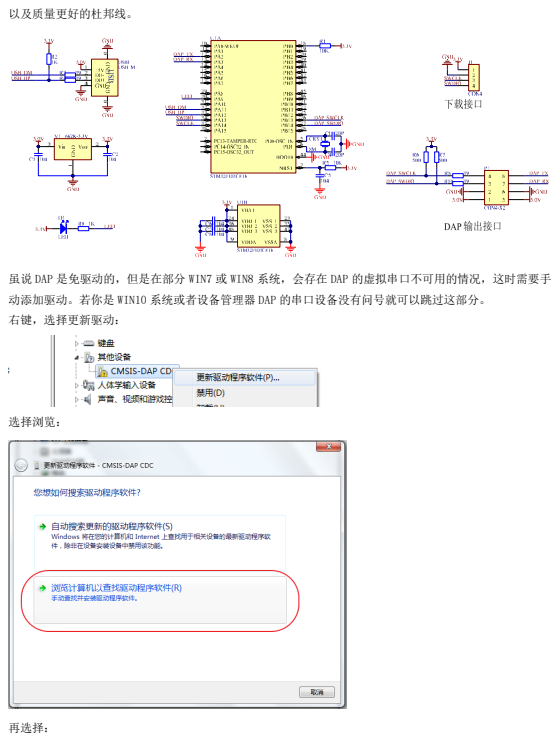
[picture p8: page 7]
以及质量更好的杜邦线。; 选择浏览：; 再选择：

虽说 DAP 是免驱动的，但是在部分 WIN7 或 WIN8 系统，会存在 DAP 的虚拟串口不可用的情况，这时需要手
动添加驱动。若你是 WIN10 系统或者设备管理器 DAP 的串口设备没有问号就可以跳过这部分。
右键，选择更新驱动：

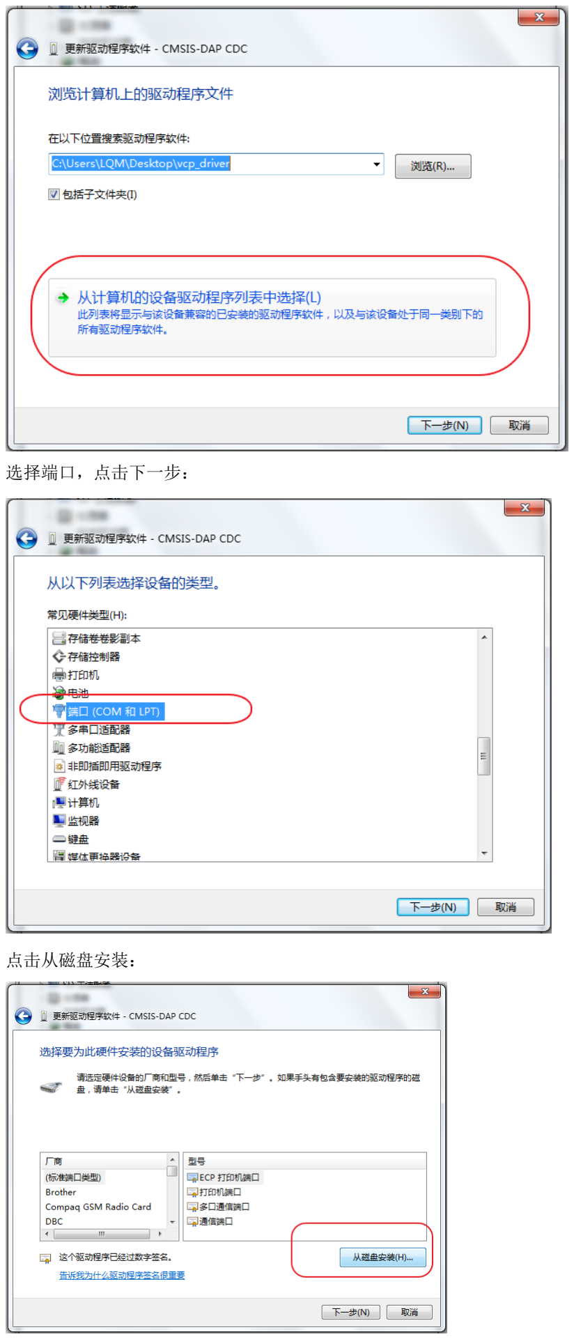
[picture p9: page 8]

选择端口，点击下一步：

点击从磁盘安装：

选择附件里 WIN7 驱动文件夹下的 stmcdc.inf

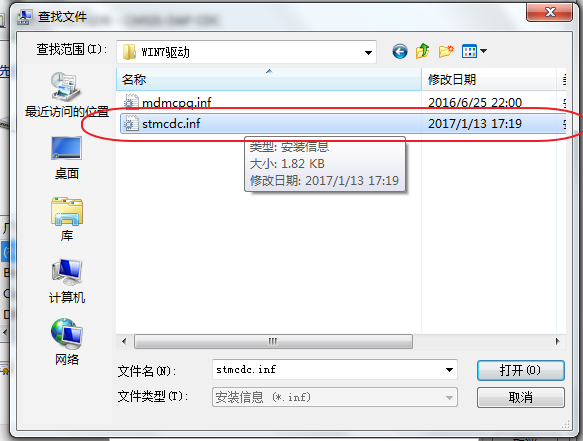
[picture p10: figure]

选择之后，点下一步，这时候会跳出警告，无视，直接安装即可，出现以下界面即安转成功。

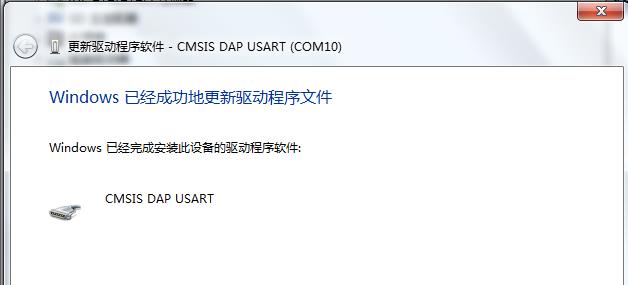
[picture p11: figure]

那么要在 MDK 里面使用 CMSIS DAP 需要简单的设置一下，点击“魔术棒”按钮：

选择仿真器，并点击 setting：

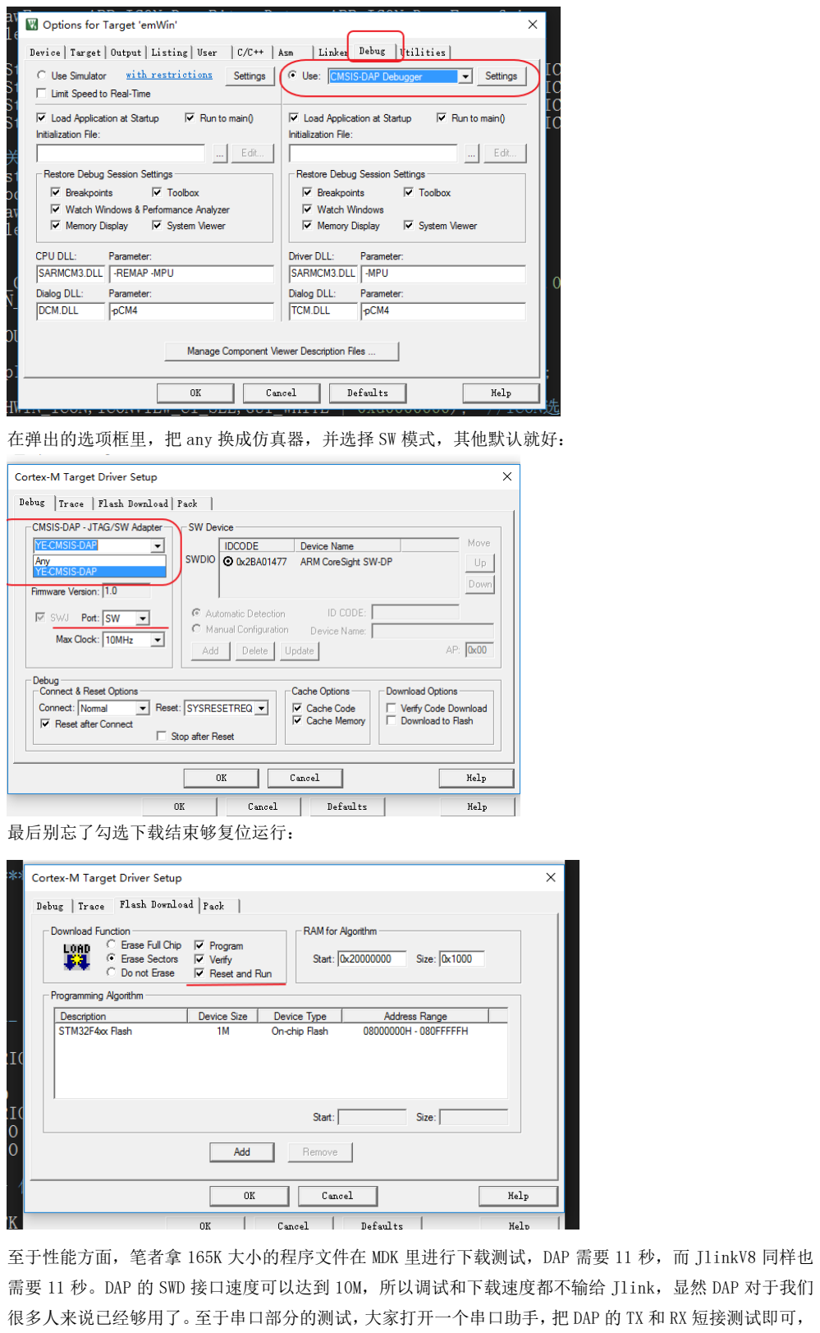
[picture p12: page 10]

在弹出的选项框里，把 any 换成仿真器，并选择 SW 模式，其他默认就好：

最后别忘了勾选下载结束够复位运行：

至于性能方面，笔者拿 165K 大小的程序文件在 MDK 里进行下载测试，DAP 需要 11 秒，而 JlinkV8 同样也 需要 11 秒。DAP 的 SWD 接口速度可以达到 10M，所以调试和下载速度都不输给 Jlink，显然 DAP 对于我们 很多人来说已经够用了。至于串口部分的测试，大家打开一个串口助手，把 DAP 的 TX 和 RX 短接测试即可，

笔者测过在波特率 1382400（此为笔者串口助手的最高波特率）下仍可正常工作。而且 CMSIS DAP 不需要 安装驱动，电脑会识别为 HID 设备，插进电脑就可以使用，同时还利用 32 的 USB 虚拟串口在实现仿真器的 同时还实现了 USB 转串口的功能，很巧妙。毕竟是开源的东西，没有版权的限制，这对于我们这些电子“屌 丝”而言无疑是福音。对于这个 DAP 仿真器笔者一直很喜欢，之前的 Jlink 已经冷落在箱底堆灰尘了。 可能有些朋友会问：怎么不加一个自恢复保险丝？因为平常开发 32 的应用经常要外接一个大的液晶屏，加 上其他的一些外设，整个系统供电经常达到 800ma，由于自恢复保险丝随着电流越大压降越大，很多时候会 让一些电路因为低压而无法工作，加之现在的电脑 USB 口都有很完善的电源保护，不必担心会因意外烧毁 USB 口。当然，你也可以按照自己的喜好重新进行设计。

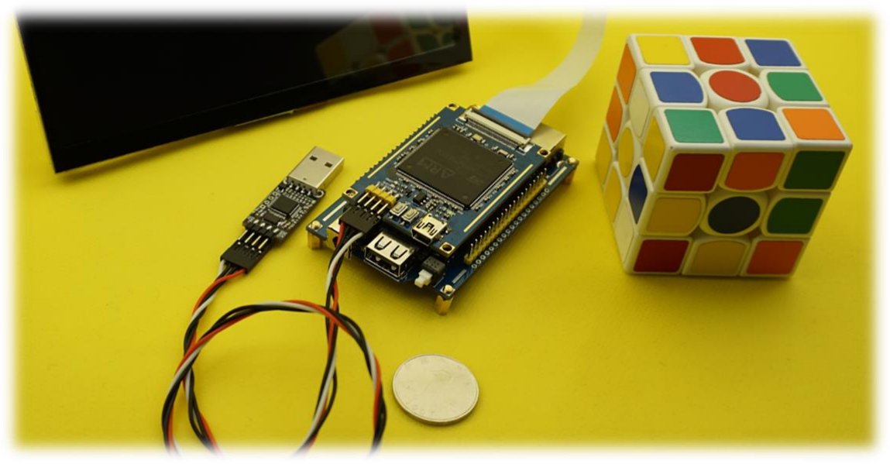
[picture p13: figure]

至此，整个 CMSIS DAP 制作介绍完成，详细的源代码以及原理图见附件。 另外，笔者在聚丰众筹发起了众筹，如果大家喜欢这个仿真器的话还请支持一下我们。 http://z.elecfans.com/103.html

反派小智
2017-3-18

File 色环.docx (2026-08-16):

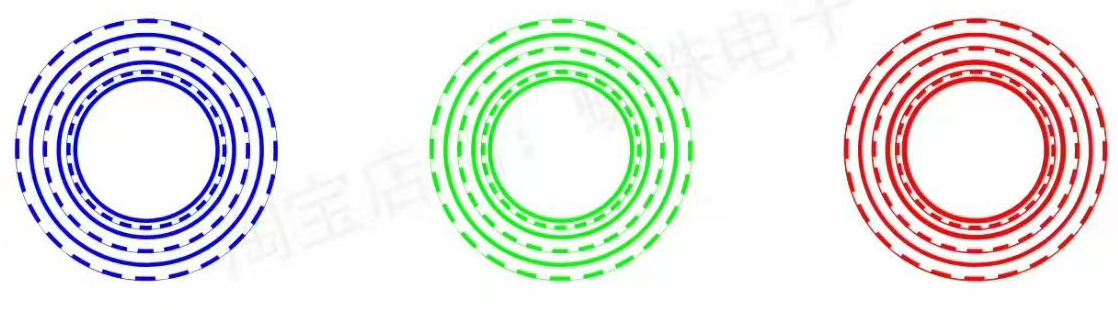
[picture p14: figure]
微信图片_20260527223632_40_41

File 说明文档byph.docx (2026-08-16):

# 1. 注意事项

①训练的地图各种元素一定要和比赛场地一样，不然现场再调已经来不及了！！！

②地图各种元素的位置，物料转盘的高度，二维码板的位置和高度，二维码的大小，现场的亮度都需要注意

③调试的时候程序进入死循环不要直接重启，要把机械臂放到初始位置，不然一上电舵机会转到初始位置，机械臂直接打到人或者车身

④碳纤维板导电，注意不要让金属物体接触到碳纤维和电子元件导致短路烧坏元件

# 2. 血泪教训

①平时训练的二维码板放置随意和现场的二维码板不一样，因为扫完码后的一个提前旋转机械臂动作打到二维码板，把机械臂的一个勾爪打爆了，现场缠胶带也没用了

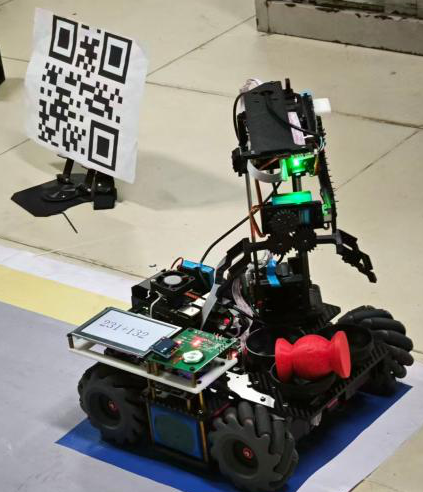
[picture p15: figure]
ce0a003c5bff8cef37c9c2309d837c45
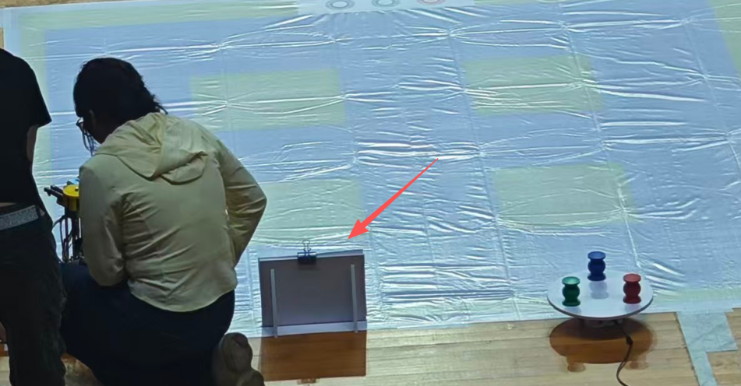
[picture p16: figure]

②实验室的物料转盘是100mm高度，现场是80mm，视觉划分的识别区域有误差，现场识别特别不灵敏

③实验室当时灯坏了，比较暗，现场灯光特别亮，识别颜色偏差大，识别特别不灵敏

④比赛前一天不要通宵，一定要好好休息，不然比赛现场特别困脑子转不动

# 3. 2026年参赛经验

比赛前几天多把初赛模拟完，不要比赛前一天通宵调，第二天要保持头脑清醒不然真有什么差错脑子也转不过来了。

比赛6分钟调试时间然后跑第一轮，每轮统一时间发车，只能发车一次，第一轮结束后调试3分钟，然后第二轮发车。

现场完赛的队伍很少，只要能跑完半程就能进决赛，初赛成绩不带入决赛，决赛完赛率也低，所以一定要求稳，不要争速度。

比赛地点广东工业大学，早上7点坐校车，8点多到。11点半前交车就行，可以在体育馆外面多检查，充电，带地图找个地方调车，可以上体育馆二楼吹空调。

每个学校每个赛项最多5个队伍，所以会打校赛。记得提前准备。

国赛年一个队4个人，一定要有人会结构，因为比赛决赛那天晚上要根据决赛赛题重新设计勾爪，还要出工程图，catia和soildworks都去学一下，我们本身就是机械大类的专业，多少了解一下。

# 4. 结构部分

## 4.1. 结构设计

公差：用到的零件在文件夹里面都找得到，自己设计零件注意公差，没公差会拼不起来

零件设计：平时上课老师带着练的零件跟着练就行了，设计的时候可以用软件里的测量工具测量尺寸，在装配图里画零件，直接装上看看能不能用

装配：学习常见的约束命令就能装一起了，soildworks打不开装配图太卡了可以用catia打开，各有各的优点。

工程图：还没找到官方的工程图文件，工程图也是上课会学的，上课的时候认真学一下，到时候决赛前一天晚上要自己出个工程图，下面是我自己画的工程图，只做参考（我不是专业的）

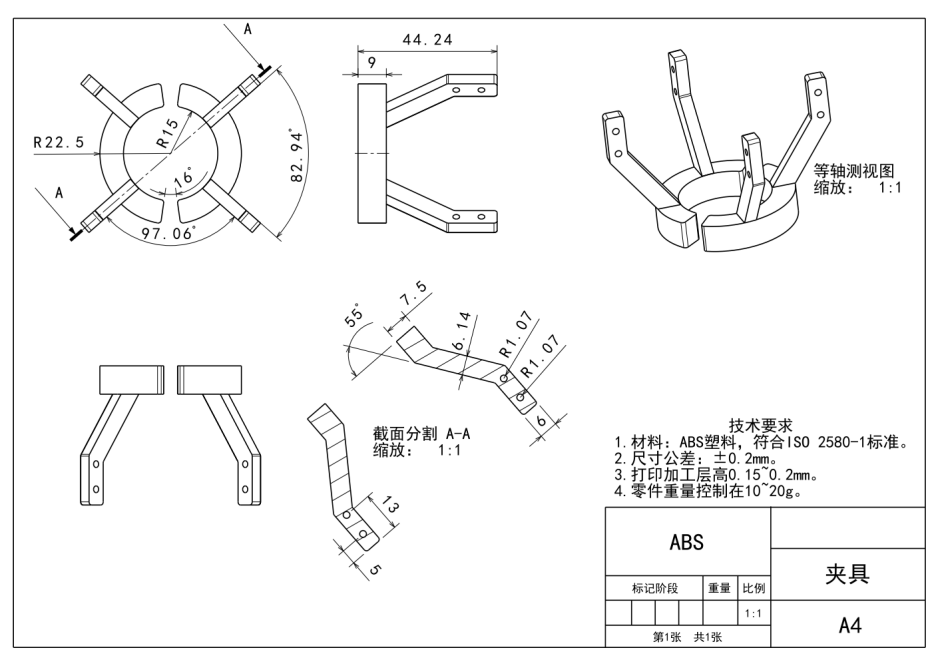
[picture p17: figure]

## 4.2. 3D打印

工程准备：手机和电脑下载拓竹软件，扫码连wifi，用登录码登录，把画好的零件直接拖到拓竹软件里就行了。把参数设置好切片，连上打印机就能打印了。可以创建一个工程打过的东西全部放里面，下次方便再打。下图是我工创赛和电赛全部打过的零件，在.3mf文件里。

耗材选择：刚度，韧性，强度，价钱综合选个合适就行，abs等材料有毒，打印的时候要通风。

参数设置：打印机初始化要6分钟，所以尽量一盘多打几个，摆盘高度差不多的放同一盘会快点，打印填充和网格样式那些网上学。

打印常见问题：实际耗材和设置耗材不一致容易出现问题，堵头，炒面，耗材可能会缠线，打印的时候多观察几下。打印之前检查打印底板上有无异物，底板是消耗品要注意保护。

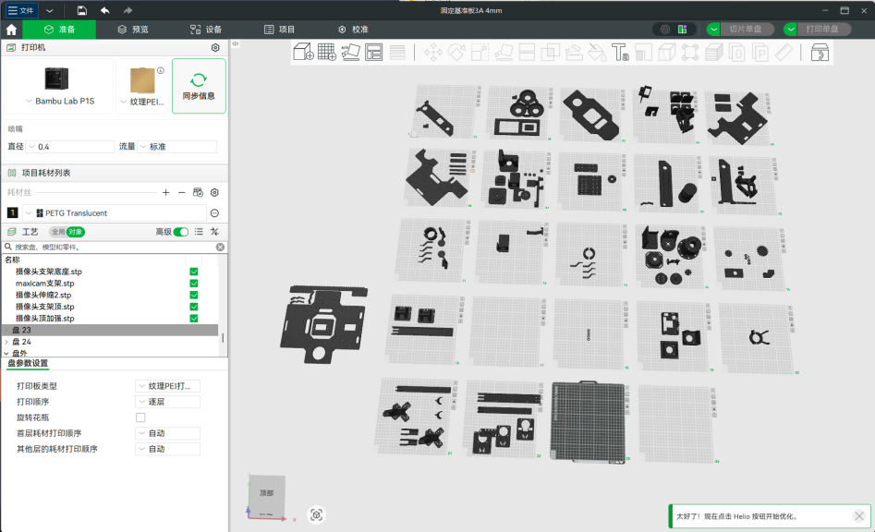
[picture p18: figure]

## 4.3. 碳纤维板玻璃纤维板

把工程文件全部发商家，商家会帮你排版，可以把小的零件放大零件空隙里，因为价钱是算最大尺寸的，如下图所示

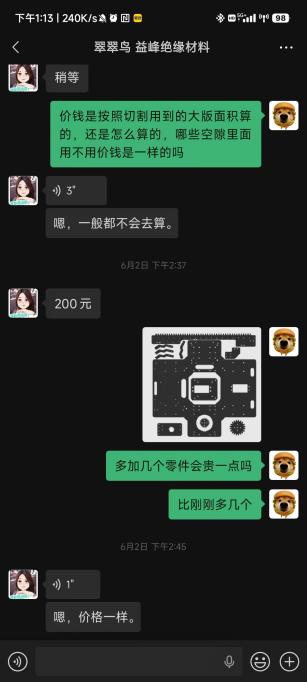
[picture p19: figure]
0b43a65967c41d17c0dd15cd99d1a9fd
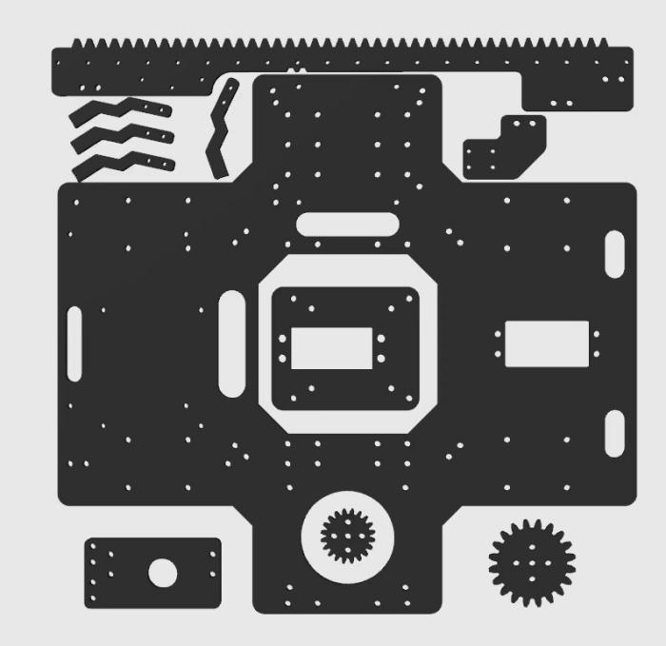
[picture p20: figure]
aeaffd184ece3e48ff6bc0cdba979dfe

## 4.4. 安装

对着装配图安装，不知道零件在哪的可以把其他零件隐藏了就能找到了，整体不难，螺丝用内六角比十字螺丝好点，好拧不容易滑丝，可以买个电动螺丝刀，全部手拧要拧半天。轮子装的时候记得看朝向，不然不能正常移动。

滑轨的滑块拆开来里面的滚珠会掉出来，所以拆装的时候要注意，尽量让滑块放在滑轨上不分离。

# 5. 电控部分

用的是stm32F4的标准库裸机开发。

如果打开工程注释是乱码就把编码换成GB2312

## 5.1. 通信协议

1. uint8_t Serial_TxPacket[9];//定义发送数据包数组，数据包格式：FF 01 02 03 04 05 06 07 08 09 FE

每帧的帧头是FF，内容为9个ASCLL码，帧尾是FE，32发送和接收的都是16进制，地瓜派会转成acsll码进行通信，可以参考下表。32收到一帧后会存到Serial_TxPacket[]，大端模式

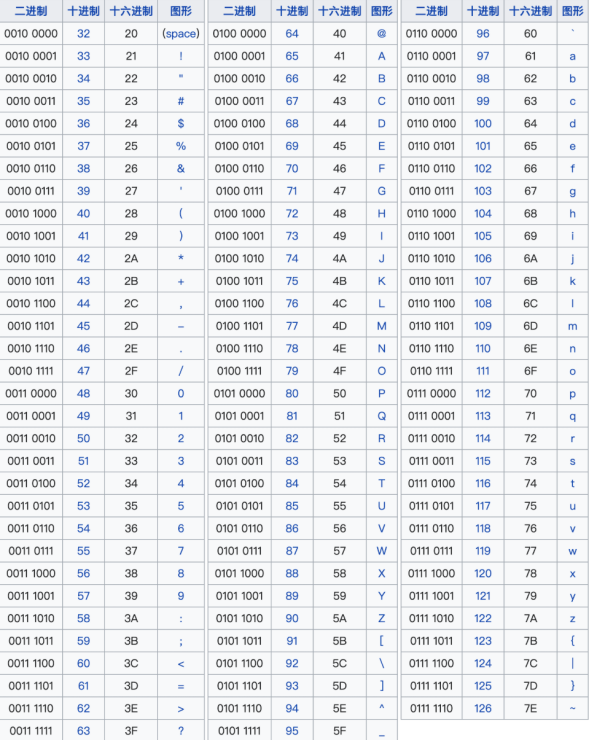
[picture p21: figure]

## 5.2. 舵机设置

### 5.2.1. 舵机使能

每次上电都会初始化固定的位置，可以设置PWM的初值在下面的函数，所以安装勾爪和物料盘的之前先上电使能舵机，然后再安装，这样每次重新上电都是当前位置。

1. /* TIM使能 */
2. TIM_Cmd(TIM2, ENABLE); // 使能TIM2，定时器开始运行
3. TIM_SetCompare2(TIM2, 520); // 抓手
4. TIM_SetCompare3(TIM2, 648); // 物块平台
5. TIM_SetCompare4(TIM2, 838); // 云台

## 5.3. 舵机差值函数

舵机移动时PWM并不是一个跳变的过程，而是用到了差值函数，把当前值和目标值直接算出了n个值去设置PWM值以达到平滑移动的效果，移动速度快慢可以改变time的值，越小越快，但是要综合稳定性，舵机

1. typedef struct {
2. float start_angle; //从什么角度开始
3. float target_angle; //目标是旋转多少角度
4. float current_angle; //当前的角度是多少
5. int moving_flag; // 插值更新标志，1: 正在运动；0: 空闲
6. float t; // 时间变量，用于插值计算
7. float time; //整个插值运动所需的时间
8. void (*SetServoAngle)(float angle); // 设置当前角度的函数指针
9. } Servo_t;
11. Servo_t yuantai = {60.84f, 0.0f, 60.84f, 0, 0, 0, Servo_SetAngle4_yuntai};
12. Servo_t zhuashou = {2.7f, 2.7f, 2.7f, 0, 0, 0, Servo_SetAngle2_zhuashou};
13. Servo_t wukuaipingtai = {20.0f, 20.0f, 20.0f, 0, 0, 0,Servo_SetAngle3_wukuaipingtai};

### 5.3.1. 舵机相关函数封装

物料盘有3个位置，勾爪开合，可以自己设置值

1. void set_wukuaipingtai_weizhi(int pos)
2. {
3. if(pos == 0x01){
4. set_wukuaipingtai_Angle(20.0f,300);
5. }else if(pos == 0x02){
6. set_wukuaipingtai_Angle(20.0f+119.0f,300);
7. }else if(pos == 0x03){
8. set_wukuaipingtai_Angle(20.0f+119.0f+117.0f,300);
9. }
10. }

## 5.4. 步进电机

校准：电机运行会抖的话可以重新校准，一般在哪用就在哪校准，电机后面有个磁铁，控制板上面有个霍尔传感器，闭环控制就得靠这两个东西

控制模式：选择CAN模式，每个步进电机都要单独设置CAN的id，其他默认设置就行

## 5.5. 底盘控制

目前能用的只有x，y和原地旋转，就是说每次只能朝一个方向移动或者原地旋转，还不能像考驾照直角转弯一样移动的同时改变方向，可以自己去学一下怎么达到这个效果，当时比赛现场有人能够做到，又帅又快。

### 5.5.1. 移动和旋转

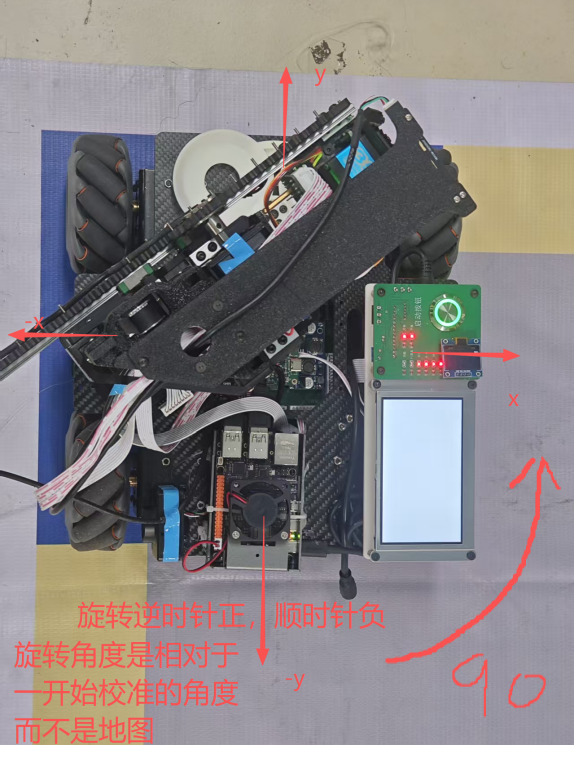
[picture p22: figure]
e2933e421da25bac43abf6996a0a6cf8

如图所示，car_move1是y方向移动car_move2是x方向移动，PID_move(0,0,0,1000,-180,3)的第4个参是自转多少度。Car_move没有闭环陀螺仪，移动的时候可能会跑偏，pid_move有闭环陀螺仪，每次自转的时候转到目标角度才会释放

car_move1(0，距离，速度，加速度），car_move会根据这几个参数计算这一步的运动时间阻塞程序car_move_delay，时间到了释放之后能执行下一步，步进电机跑快了会抖和丢步，速度合适就行

1. //当y>0时左移
2. void car_move1(float x,float y,int a_in,int car_speed)
3. {
4. delay_ms1(10);
5. change_SNA1(a_in,car_speed);
6. car_move_distance_y(-y);
7. car_move_delay(y,a_in,car_speed,1);
8. }

## 5.6. 机械臂控制

平推就是控制齿轮齿条，正值向前，负值向后，升降控制皮带，初始位置在最上面，正值向下。云台是控制舵机角度，从小到大，逆时针。speed_of_yuntai默认13，。move_all是阻塞运行，通过比较3个自由度最大的运行时间也就是time，time1，time3，等待最慢的一个自由度运行完之后才释放，move_all1是非阻塞运行，只发命令不管有没有运行完就执行下一个函数（move_all后面加一个数字1）

1. /*前三个参数分别为
2. 平推的目标位置：65.0f 到 -122.0 之间
3. 平推的速度： 1000 rpm
4. 平推的加速度：200rpm
5. 中间三个参数分别为
6. 升降的目标位置：0.0f 到 130.0f
7. 升降的速度：1000 rpm
8. 升降的加速度：200 rpm
9. 最后两个参数分别为
10. 云台的目标位置：0 到 360
11. 云台的转速：13左右
13. */
14. int move_all(float target_pos, uint16_t speed, uint8_t accel,float target_pos1, uint16_t speed1, uint8_t accel1,float target, float speed_of_yuntai)
15. {
16. accel1 = 240;
17. accel = 230;
18. speed1 = 2000;
19. double time1 = pingtui_control(target_pos,speed,accel);
20. double time2 = shengjiang_control(target_pos1,speed1,accel1);
21. double time;
22. if(fabs(target - yuantai.current_angle) <= 28){
23. time = 120 * fabs(target - yuantai.current_angle)/13.0f;
24. }else if(fabs(target - yuantai.current_angle) <= 50){
25. time = 100 * fabs(target - yuantai.current_angle)/13.0f;
26. }else if(fabs(target - yuantai.current_angle) <= 100){
27. time = 85 * fabs(target - yuantai.current_angle)/13.0f;
28. }else if(fabs(target - yuantai.current_angle) <= 150){
29. time = 70 * fabs(target - yuantai.current_angle)/13.0f;
30. }else if(fabs(target - yuantai.current_angle) <= 250){
31. time = 60 * fabs(target - yuantai.current_angle)/13.0f;
32. }else{
33. time = 50 * fabs(target - yuantai.current_angle)/13.0f;
34. }
35. set_yuantai_Angle(target,time);
36. double max = fmax(time, fmax(time1, time2));
37. delay_ms1((int)max);
38. return (int)max;
39. }

## 5.7. 视觉定位

每次上位机发过来的位置坐标都是固定的，如果要改变每次定位的位置，可以改

1. x_origin = x_origin - 322;
2. y_origin = y_origin - 165;

这两行后面-的数，这样就可以改变每次定位的位置，怎么改参照移动和旋转中的图

上位机发过来位置信息：

1. 3：
2. \u53d1\u9001: b'\xff030102523\xfe' //x坐标301，y坐标252
3. 1：
4. \u53d1\u9001: b'\xff030402361\xfe' //x坐标304，y坐标236
5. 2：
6. \u53d1\u9001: b'\xff030402392\xfe' //x坐标304，y坐标239

读出来就是蓝色物块x坐标301，y坐标252，红色物块x坐标304，y坐标236 ，绿色物块x坐标304，y坐标239

3. void transfer_position_wukuai(uint8_t task_choose,float distance,uint8_t color)
4. {
5. x_origin = (Serial_RxPacket[0]-0x30)*1000+(Serial_RxPacket[1]-0x30)*100+(Serial_RxPacket[2]-0x30)*10+(Serial_RxPacket[3]-0x30);
6. y_origin = (Serial_RxPacket[4]-0x30)*1000+(Serial_RxPacket[5]-0x30)*100+(Serial_RxPacket[6]-0x30)*10+(Serial_RxPacket[7]-0x30);
7. float bilichi = 0;
8. if(task_choose == 0x01){
9. bilichi = -0.0035f*(distance+80.0f) + 1.1967f;
10. x_origin = x_origin - 322;
11. y_origin = y_origin - 165;
12. }else if(task_choose == 0x02){
13. bilichi = -0.0033f*(distance) + 1.1655f;
14. x_origin = x_origin - 314;
15. y_origin = y_origin - 238;
16. }

启动准备程序：
上位机启动程序后会向32发送一帧987654321，其中第一位是9第二位是8，在if语句中为真执行break跳出循环，等待swith_out() == 1也就是按下按钮就可以执行下面的程序了。

1. while(1){
2. LED_Toggle2();
3. delay_ms1(200);
4. if((Serial_RxPacket[0]==0x39) && (Serial_RxPacket[1]==0x38)){
5. break;
6. }
7. }
8. /**************************指示灯闪烁，可以开始***************************//
9. while(swith_out() == 1){
10. LED_Toggle2();
11. delay_ms1(50);
12. }//树莓派已经准备好，按下开关即可启动
13. mypid.integral = 0;
14. WHT101_ANGLEZCali();//101z轴置零

扫描二维码

32给上位机发送0x31，转成ascll也就是“1”，执行任务1

car_move(距离，距离，速度，加速度），car_move会根据这几个参数计算这一步的运动时间阻塞程序，时间到了释放之后能执行下一步

等待接收标志位置1然后接收上位机发过来的任务码并储存到数组里

1. Serial_GetRxFlag();Serial_SendByte(0x31);
2. //***************************第一部分，识别二维码并显示，大致移动到原料区*********************//
3. //扫二维码
4. car_move2(150,0,150,150);
5. car_move1(0,-530,150,200);
6. //读取树莓派信息
7. while(1){
8. if (Serial_GetRxFlag() == 1){ //收到数据包
9. sprintf(tjcstr, "t0.txt=\"%d%d%d+%d%d%d \"",
10. Serial_RxPacket[0]-0x30,Serial_RxPacket[1]-0x30,Serial_RxPacket[2]-0x30,
11. Serial_RxPacket[4]-0x30,Serial_RxPacket[5]-0x30,Serial_RxPacket[6]-0x30);
12. HMISends(tjcstr);
13. HMISendb(0xff);//在显示屏上面显示任务
14. break;
15. }
16. }
17. task[0]= Serial_RxPacket[0]-0x30;task[1] = Serial_RxPacket[1]-0x30;task[2] = Serial_RxPacket[2]-0x30;
18. task[3]= Serial_RxPacket[4]-0x30;task[4] = Serial_RxPacket[5]-0x30;task[5] = Serial_RxPacket[6]-0x30;

在物料盘抓取物块

1. set_wukuaipingtai_weizhi(0x01);
2. //****************************调整(亮度等参数)****************************//
3. TIM_SetCompare1(TIM3,300);
4. //********************第二部分，识别物块颜色，按照指定的顺序搬运**************************//
5. //复位到识别的位置
6. move_all1(-120.0f,1000,200 ,0,2000,200 ,278,13);
7. set_zhuashou_kai();
9. car_move1(0,-1000+90,150,200);
10. move_all1(40.0f,1000,200 ,0,2000,200 ,278,13);
11. //提前发送命令2
12. Serial_GetRxFlag();Serial_SendByte(0x32);
13. car_move2(-30,0,100,100);
14. while(1){
15. while(1){
16. if(Serial_GetRxFlag() == 1){
17. break; //是wait发送的分解
18. }
19. }
20. //0x01代表选择的是转盘上的物块，70.0f是物块的高度，0x00代表不选择颜色
21. transfer_position_wukuai(0x01,70.0f,0x00);
22. car_move_distance(direct_x,direct_y,100,80);
23. if(Serial_RxPacket[8] != 0x34){
24. break;
25. }else{
26. wait_send_shumeipai(0x32,15000);
27. }
28. }
29. move_all(60.0f,1000,200 ,0,2000,200 ,278,13);
30. wait_send_shumeipai(0x33,20000); //识别圆盘上要抓物块的顺序
31. ypcode[0]= Serial_RxPacket[0]-0x30;ypcode[1] = Serial_RxPacket[1]-0x30;ypcode[2] = Serial_RxPacket[2]-0x30;
32. //1.圆台拿走第一个物块
33. set_wukuaipingtai_weizhi(0x01);
34. yuantai_na(ypcode[0]);
36. //2.圆台拿走第二个物块
37. set_wukuaipingtai_weizhi(0x02);
38. yuantai_na1(ypcode[1]); //达到指定的识别的位置
39. //判断物块是否静止
40. wait_send_shumeipai(0x35,30000);
41. while(1){
42. if(Serial_RxPacket[0] == 0x39 && Serial_RxPacket[1] == 0x38){
43. break;
44. }
45. }Serial_RxPacket[0] = 0x30;Serial_RxPacket[1] = 0x30;
46. yuantai_na2(ypcode[1]); //一旦识别到物块静止，抓物块到物块平台上
48. //3.圆台拿走第三个物块
49. set_wukuaipingtai_weizhi(0x03);
50. yuantai_na1(ypcode[2]); //达到指定的识别的位置
51. //判断物块是否静止
52. wait_send_shumeipai(0x36,30000);
53. while(1){
54. if(Serial_RxPacket[0] == 0x39 && Serial_RxPacket[1] == 0x38){
55. break;
56. }
57. }Serial_RxPacket[0] = 0x30;Serial_RxPacket[1] = 0x30;
58. yuantai_na2(ypcode[2]); //一旦识别到物块静止，抓物块到物块平台上
60. TIM_SetCompare1(TIM3,0); //关闭补光灯
61. //复位到识别的位置
62. set_wukuaipingtai_weizhi(0x01);
63. move_all1(-120.0f,1000,200 ,0,1000,200 ,278,13);
64. set_zhuashou_kai();

# 6. PCB部分

实验室现有的HWT101是有扩展板的，把模块拆下来费劲，一个300多块钱怕拆坏，所以我画了个转接板在下面，一样能插在对应的孔位上

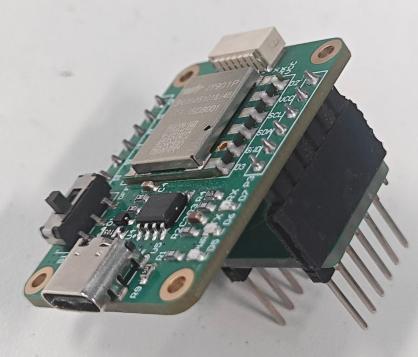
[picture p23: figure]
482ffbd8acbe4ef360fce138c5171070

有时间可以给集成板PCB优化一下，加一个控制机械臂舵机开关的，每次调试的时候复位太麻烦了，要是能够直接开关那个舵机的电源就方便很多。

# 7. 设计报告

文档写好看点，哪怕内容只是看的人只是一扫而光，样式，排版和图都规范，让别人看的舒服而不是一眼就觉得写这个报告的队是个没水平的。虽然说大家的分都差不多，但总有好坏之分，不要当最次的分母。

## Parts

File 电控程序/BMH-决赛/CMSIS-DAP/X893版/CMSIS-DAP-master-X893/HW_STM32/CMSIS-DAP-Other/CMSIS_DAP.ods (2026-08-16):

 | CMSIS_DAP.sch
RefDes | Value | Count
--------------- | --------------- | ------
C13 | SMD-0805-X7R-0.01uF-50V | 1
C2 | SMD-0805-X7R-0.1uF-50V | 7
C3
C5
C6
C7
C8
C14
C9 | SMD-0805-NP0-12pF | 2
C10
C11 | SMD-0805-NP0-18pF | 2
C12
C1 | SMD3216-10uF-16V-A | 2
C4
DD1 | STM32F103C8T6 | 1
DA1 | LP2985AIM5-3.0 (LP2981-3.0) | 1
R5 | SMD-0603-1k | 2
R13
R24 | SMD-0603-1M | 1
R1 | SMD-0603-1.5k | 1
R14 | SMD-0603-2.2k | 1
R11 | SMD-0603-2.2M | 1
R9 | SMD-0603-3.3 | 1
R2 | SMD-0603-10k | 5
R15
R16
R19
R23
R22 | SMD-0603-22 | 1
R7 | SMD-0603-22k | 2
R20
R3 | SMD-0603-36k | 1
R4 | SMD-0603-47k | 1
R17 | SMD-0805-1k | 2
R18
R12 | SMD-0805-10 | 1
R6 | SMD-0805-5k | 1
R21 | SMD-0805-22 | 1
R8 | SMD-1206-22 | 2
R10
VD2 | FYLS-0805 (GREEN) | 1
VD1 | FYLS-0805 (RED) | 1
VT1 | BC817 | 2
VT2
XP5 | BH-10 | 1
XP2 | PLS-2 | 3
XP3
XP4
XP1 | PLS-4 | 2
XP6
XS1 | USB_B | 1
ZQ1 | KX38T-32768Hz | 1
ZQ2 | HC49/u-8.000MHz | 1

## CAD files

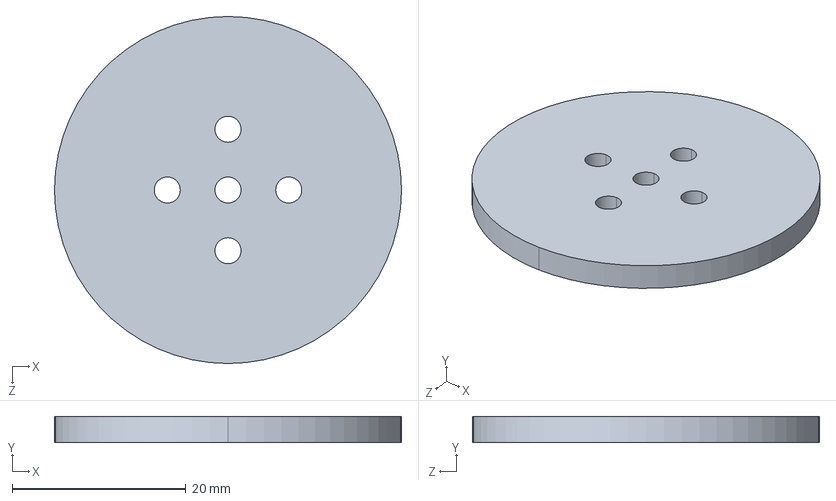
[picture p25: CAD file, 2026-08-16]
打印部件/置物盘2A垫高.STEP
40.0 x 3.00 x 40.0 mm

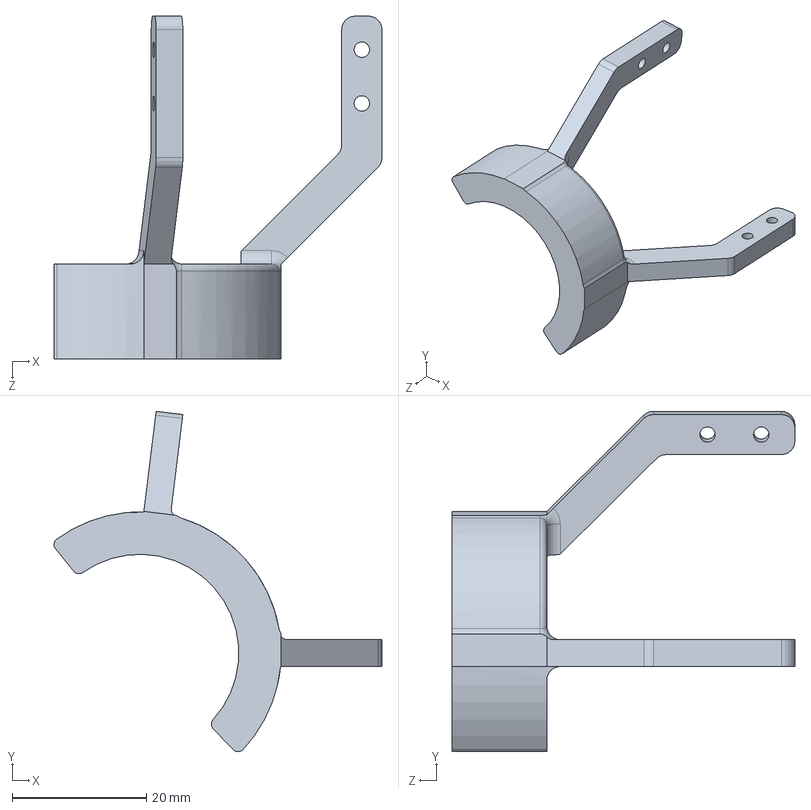
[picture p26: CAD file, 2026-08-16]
结构件/四爪夹爪环形.SLDPRT
48.8 x 50.6 x 51.0 mm

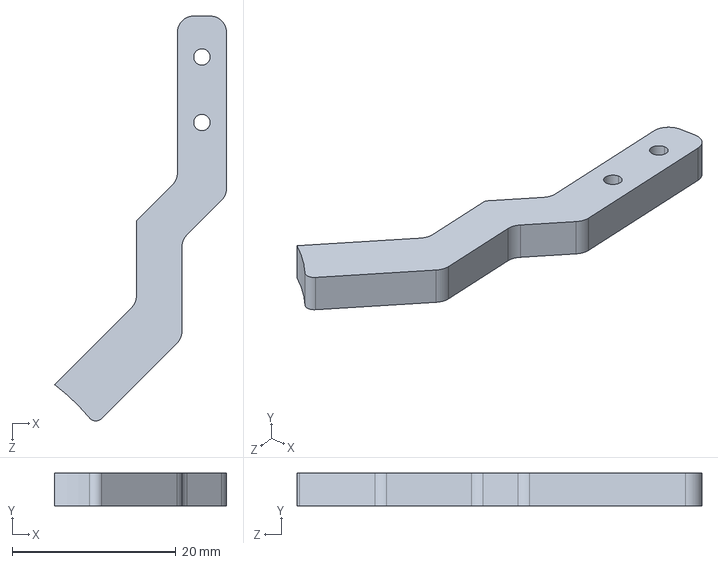
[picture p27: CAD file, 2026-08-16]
打印部件/四爪夹爪 4mm.STEP
21.0 x 4.00 x 49.4 mm

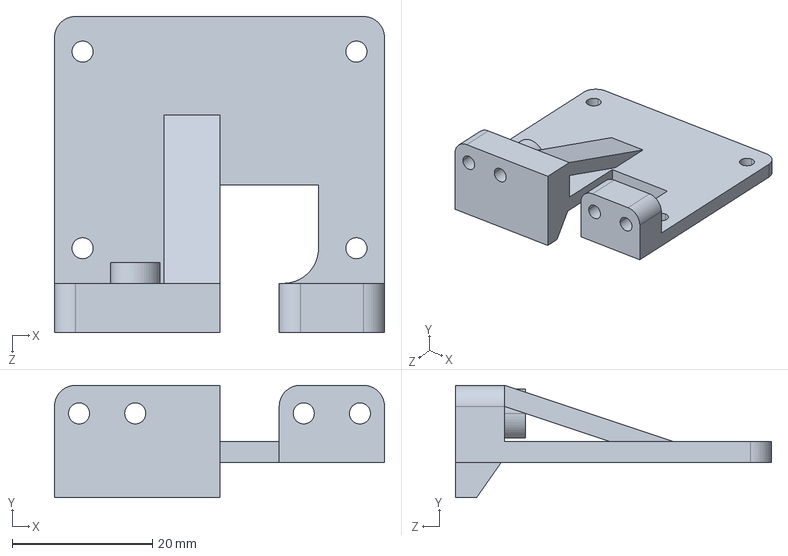
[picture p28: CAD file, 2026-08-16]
打印部件/二维码摄像头固定板C.STEP
47.0 x 16.0 x 45.0 mm

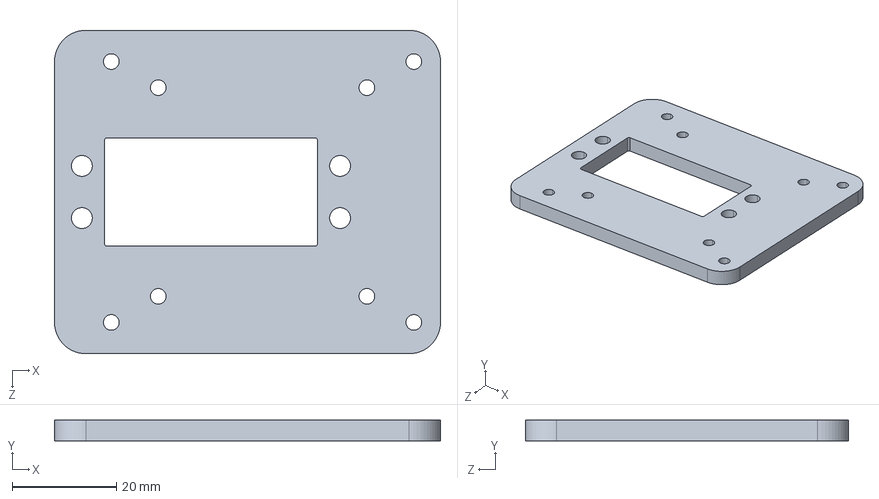
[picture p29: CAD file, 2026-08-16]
打印部件/舵机固定小板3A 4mm.STEP
74.0 x 4.00 x 62.0 mm

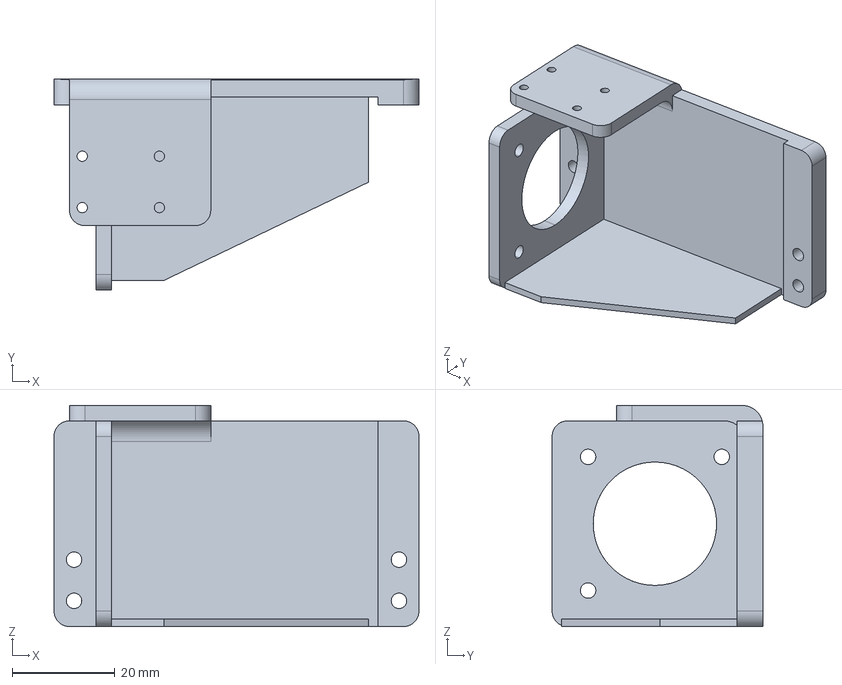
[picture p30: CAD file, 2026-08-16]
打印部件/35电机平台.stp
71.0 x 41.0 x 43.0 mm

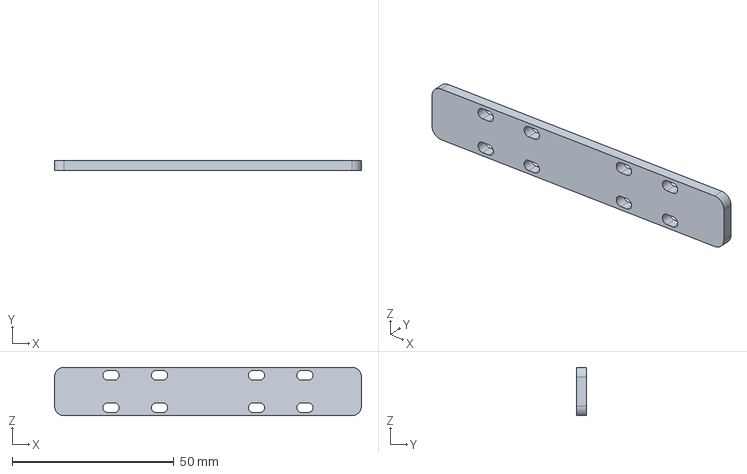
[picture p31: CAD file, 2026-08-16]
打印部件/lianjie3.stp
95.0 x 3.00 x 15.0 mm

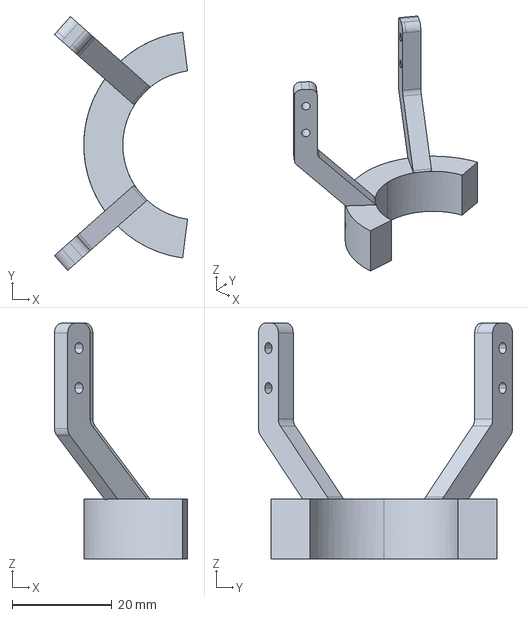
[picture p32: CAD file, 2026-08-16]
打印部件/圆勾爪30.stp
26.7 x 50.9 x 47.2 mm

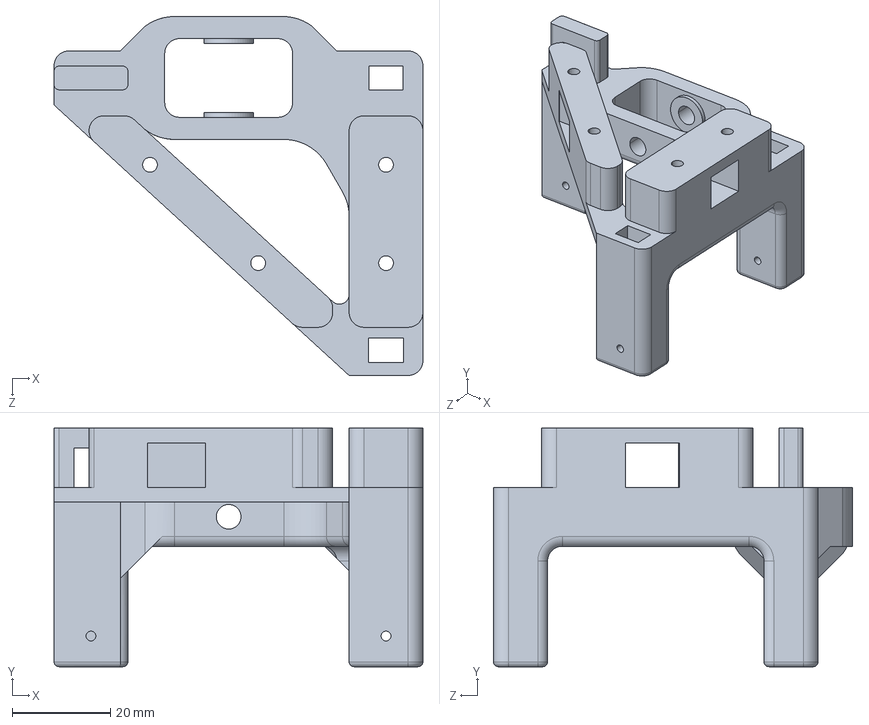
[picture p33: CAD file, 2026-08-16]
打印部件/从动同步轮固定架3A1.STEP
75.0 x 48.5 x 73.0 mm

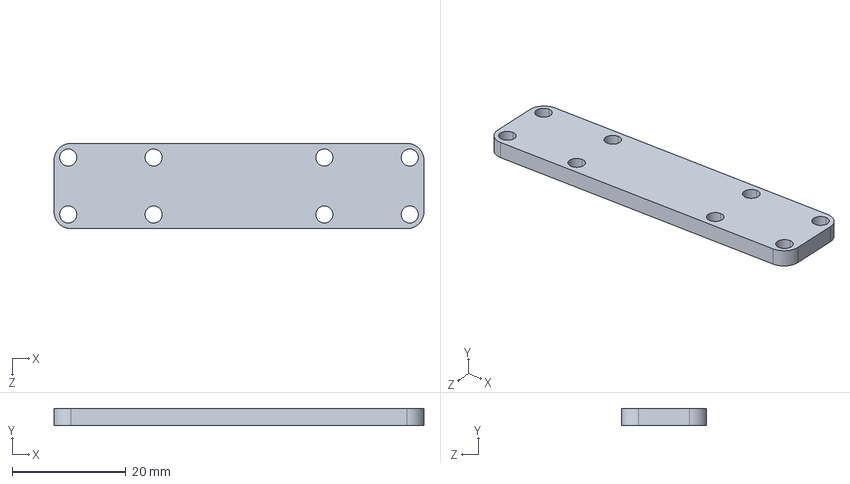
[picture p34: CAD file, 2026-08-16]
打印部件/底板连接件3.STEP
65.0 x 3.00 x 15.0 mm

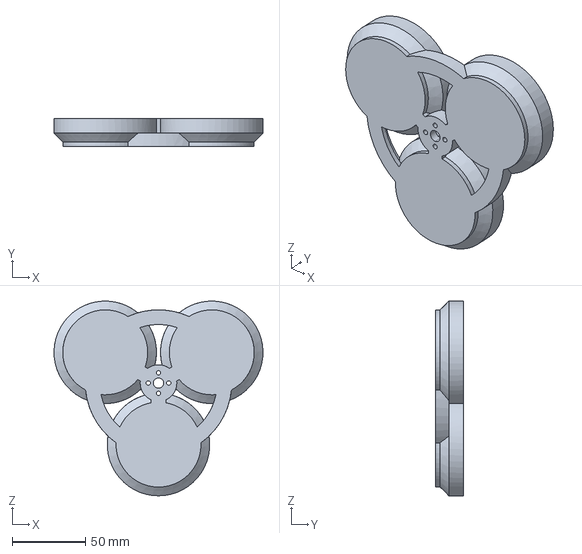
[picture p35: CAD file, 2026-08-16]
打印部件/置物盘3AHIGH.stp
142.7 x 19.0 x 132.9 mm

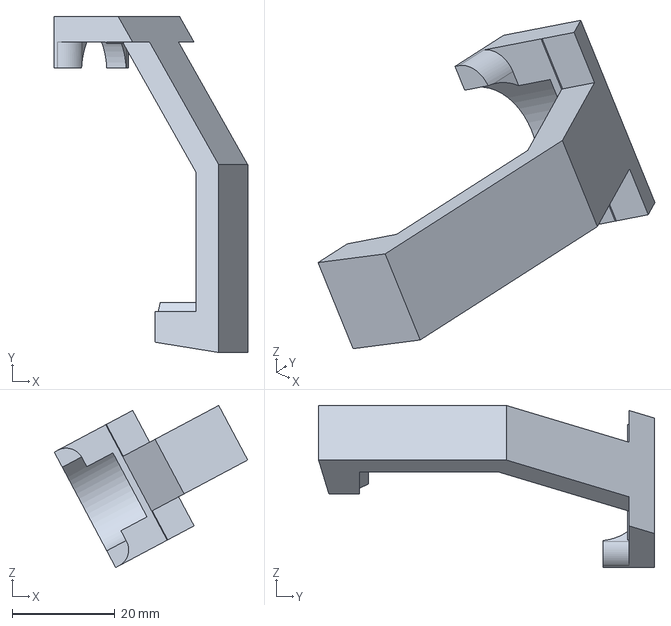
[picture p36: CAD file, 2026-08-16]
打印部件/gudinggouzhua.stp
37.6 x 65.2 x 31.5 mm

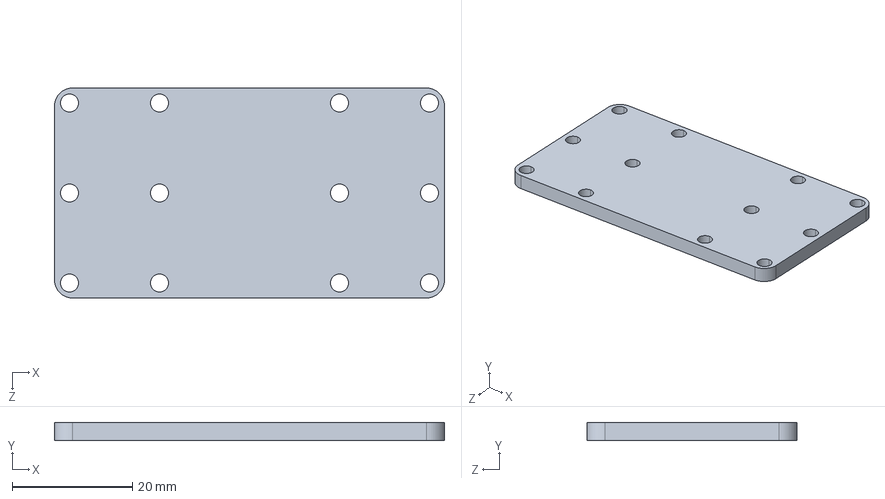
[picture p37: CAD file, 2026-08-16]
打印部件/底板连接件2.STEP
65.0 x 3.00 x 35.0 mm

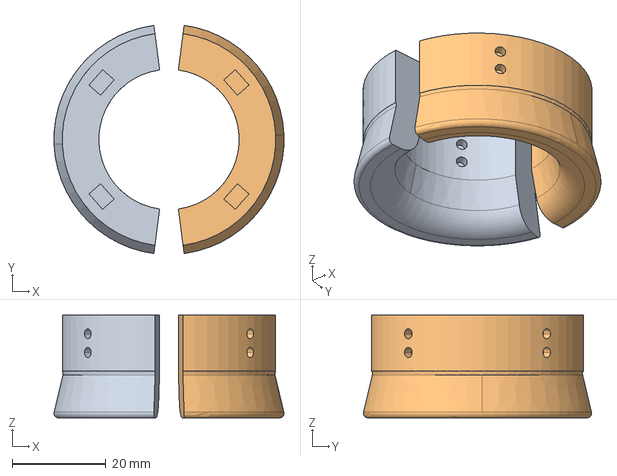
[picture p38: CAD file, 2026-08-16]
打印部件/30mm物块勾爪下2.stp
49.2 x 48.8 x 22.0 mm

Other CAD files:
打印部件/手爪舵机固定架.STEP
打印部件/齿轮20x1.25 舵机法兰盘.STEP
打印部件/圆勾爪.stp
打印部件/Part5.stp
打印部件/1.CATPart
打印部件/2mm勾爪.stp
打印部件/2mm勾爪上.stp
打印部件/30mm圆勾爪.stp
打印部件/42步进电机支架.STEP
打印部件/A固定基准板3A 4mm.STEP
打印部件/B固定基准板3A 4mm.STEP
打印部件/Part1.CATPart
打印部件/Part1.stp
打印部件/Part108.CATPart
打印部件/Part2.CATPart
打印部件/Part2.stp
打印部件/Part3.CATPart
打印部件/Part3.stp
打印部件/Part4.CATPart
打印部件/Part4.stp
打印部件/Part5.CATPart
打印部件/Part6.CATPart
打印部件/Part7.CATPart
打印部件/Product1.CATProduct
打印部件/Product3.CATProduct
打印部件/Product4.CATProduct
打印部件/Product5.CATProduct
打印部件/congdonggudingjia3A1.CATPart
打印部件/congdonggudingjia3A1.stp
打印部件/dihuan.CATProduct
打印部件/lianjie1.CATPart
打印部件/lianjie1.stp
打印部件/lianjie2.CATPart
打印部件/lianjie2.stp
打印部件/lianjie3.CATPart
打印部件/yuanhuchi.CATPart
打印部件/yuanhuchi.stp
打印部件/zhua.CATPart
打印部件/zhua.stp
打印部件/zhua111.CATProduct
打印部件/zhuangpei.CATProduct
打印部件/zhuangpei111.CATProduct
打印部件/zwp3A.CATPart
打印部件/串口屏固定板.STEP
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

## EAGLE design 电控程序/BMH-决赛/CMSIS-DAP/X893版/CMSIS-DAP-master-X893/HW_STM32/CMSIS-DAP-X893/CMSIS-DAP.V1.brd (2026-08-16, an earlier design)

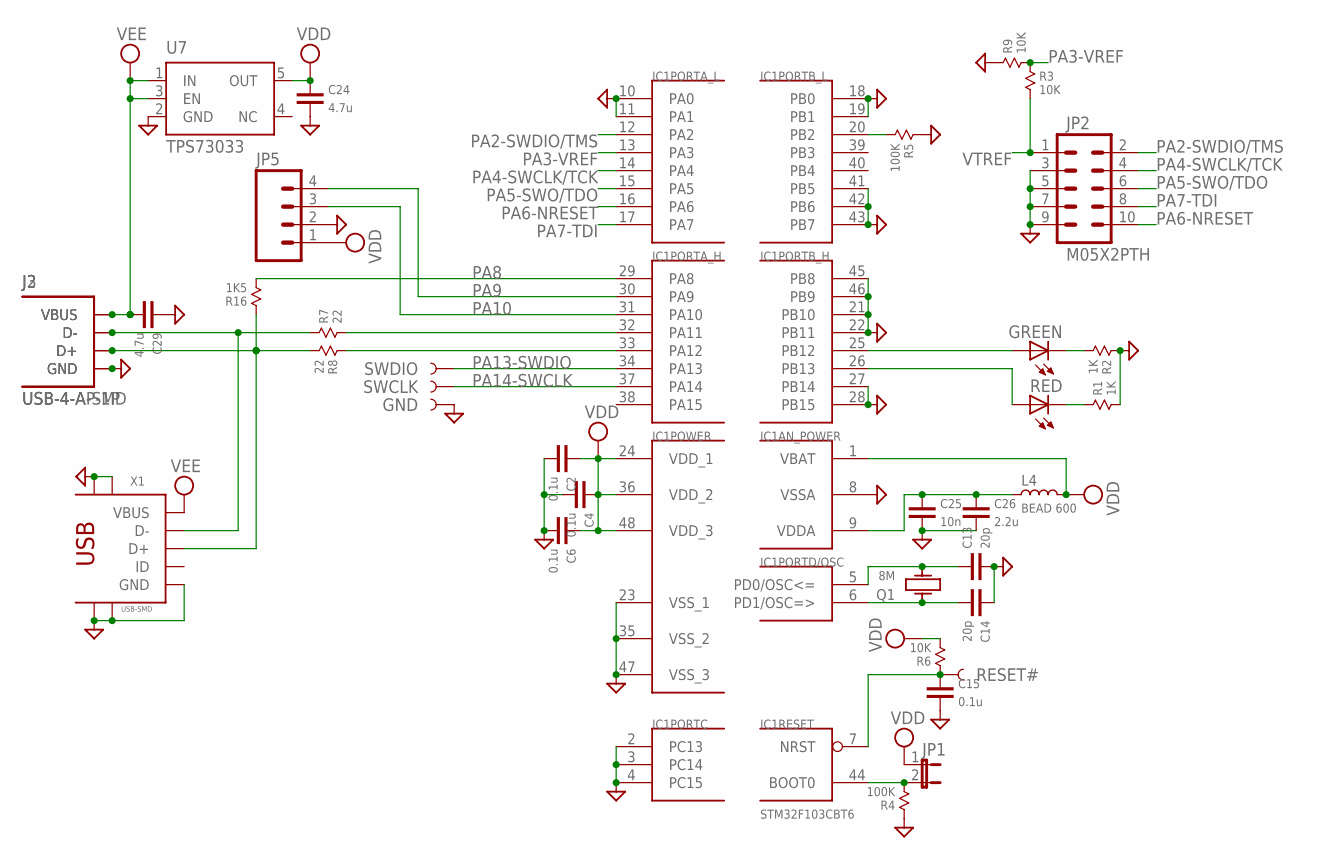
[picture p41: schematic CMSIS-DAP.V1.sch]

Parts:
C2, C4, C6, C15: 0.1u; 0603
C13, C14: 20p; 0603
C24, C29: 4.7u; 0603
C25: 10n; 0603
C26: 2.2u; 0603
GND: TEST-POINT1; PAD.1X1
GREEN: LEDCHIPLED_0603; CHIPLED_0603
IC1: STM32F103CBT6; TQFP48
J2: USB-4-AP-1P; USBAP-1P
J3: USB-4-A-SMD; USB-A-SMD
JP1: JUMPER-2SMD-NO; SJ_2S-NO
JP2: M05X2PTH; AVR_ICSP
JP5: M04PTH; 1X04
L4: BEAD 600; 0603
Q1: 8M; KX-9A
R1, R2: 1K; 0603
R3, R6, R9: 10K; 0603
R4, R5: 100K; 0603
R7, R8: 22; 0603
R16: 1K5; 0603
RED: LEDCHIPLED_0603; CHIPLED_0603
RESET#: TEST-POINT3; PAD.03X.03
SWCLK: TEST-POINT1; PAD.1X1
SWDIO: TEST-POINT1; PAD.1X1
U7: TPS73033; SOT23-5
X1: USB-SMD; USB-MINIB

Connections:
BOOT0: IC1.44 (BOOT0), JP1.2, R4.2
GND: C2.1, C4.1, C6.1, C13.1, C14.2, C15.1, C24.1, C25.1, C26.1, C29.2, GND.P$1, IC1.2 (PC13), IC1.3 (PC14), IC1.4 (PC15), IC1.8 (VSSA), IC1.10 (PA0), IC1.11 (PA1), IC1.18 (PB0), IC1.19 (PB1), IC1.21 (PB10), IC1.22 (PB11), IC1.23 (VSS_1), IC1.27 (PB14), IC1.28 (PB15), IC1.35 (VSS_2), IC1.41 (PB5), IC1.42 (PB6), IC1.43 (PB7), IC1.45 (PB8), IC1.46 (PB9), IC1.47 (VSS_3), J2.GND, J3.GND, JP2.3, JP2.5, JP2.7, JP2.9, JP5.2, R1.2, R2.1, R4.1, R5.1, R9.1, U7.2 (GND), X1.GND, X1.GND@1 (GND), X1.GND@2 (GND), X1.GND@3 (GND), X1.GND@4 (GND)
unnamed: R1.1, RED.C
unnamed: C25.2, C26.2, IC1.9 (VDDA), L4.1
unnamed: J2.D-, J3.D-, R7.1, X1.D-
unnamed: GREEN.C, R2.2
unnamed: J2.D+, J3.D+, R8.2, R16.1, X1.D+
OSCIN: C14.1, IC1.6 (PD1/OSC=>), Q1.1
OSCOUT: C13.2, IC1.5 (PD0/OSC<=), Q1.3 (2)
PA2-SWDIO/TMS: IC1.12 (PA2), JP2.2
PA3-VREF: IC1.13 (PA3), R3.1, R9.2
PA4-SWCLK/TCK: IC1.14 (PA4), JP2.4
PA5-SWO/TDO: IC1.15 (PA5), JP2.6
PA6-NRESET: IC1.16 (PA6), JP2.10
PA7-TDI: IC1.17 (PA7), JP2.8
PA8: IC1.29 (PA8), R16.2
PA9: IC1.30 (PA9), JP5.4
PA10: IC1.31 (PA10), JP5.3
PA11: IC1.32 (PA11), R7.2
PA12: IC1.33 (PA12), R8.1
PA13-SWDIO: IC1.34 (PA13), SWDIO.P$1
PA14-SWCLK: IC1.37 (PA14), SWCLK.P$1
PB2/BOOT1: IC1.20 (PB2), R5.2
PB12: GREEN.A, IC1.25 (PB12)
PB13: IC1.26 (PB13), RED.A
RESET#: C15.2, IC1.7 (NRST), R6.1, RESET#.P$1
VDD: C2.2, C4.2, C6.2, C24.2, IC1.1 (VBAT), IC1.24 (VDD_1), IC1.36 (VDD_2), IC1.48 (VDD_3), JP1.1, JP5.1, L4.2, R6.2, U7.5 (OUT)
VEE: C29.1, J2.VBUS, J3.VUSB (VBUS), U7.1 (IN), U7.3 (EN), X1.VBUS
VTREF: JP2.1, R3.2

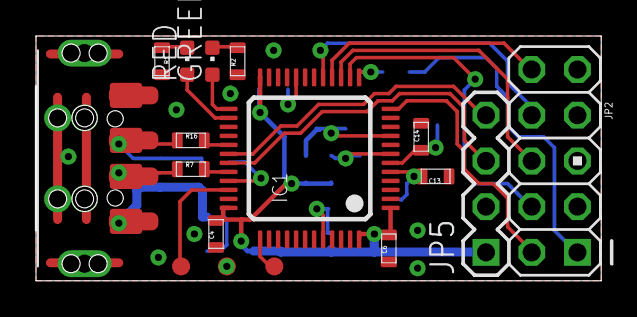
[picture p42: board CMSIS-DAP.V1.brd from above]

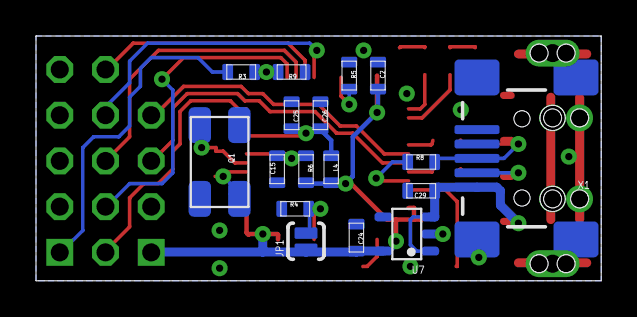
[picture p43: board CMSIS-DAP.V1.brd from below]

Board: 2 copper layers, 31.4 x 13.6 mm, 36 parts (18 on the bottom side), 29 nets.

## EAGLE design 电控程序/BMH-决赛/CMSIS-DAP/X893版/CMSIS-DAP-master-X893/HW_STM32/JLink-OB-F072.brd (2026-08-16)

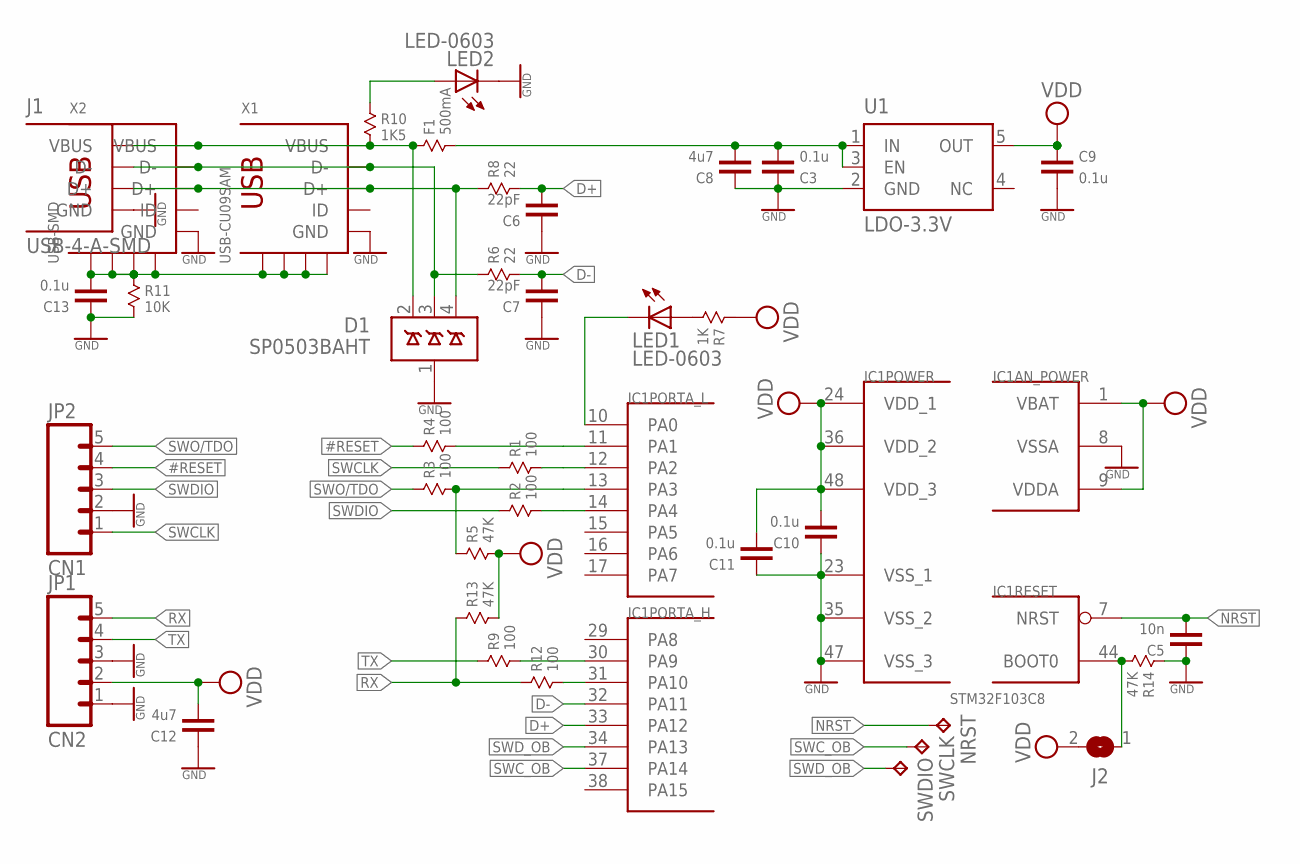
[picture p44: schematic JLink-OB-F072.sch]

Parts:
C3, C9, C10, C11, C13: 0.1u; 0603
C5: 10n; 0603
C6, C7: 22pF; 0603
C8, C12: 4u7; 0603
D1: SP0503BAHT; SOT143
F1: 500mA; 0805
IC1: STM32F103C8; TQFP48
J1: USB-4-A-SMD; USB-A-SMD
J2: JUMPER2-0402-NC; JUMPER2-0402_NC
JP1: CN2; 1X05
JP2: CN1; 1X05
LED1, LED2: LED-0603; CHIPLED_0603
NRST: TPTP10R; TP10R
R1, R2, R3, R4, R9, R12: 100; 0603
R5, R13, R14: 47K; 0603
R6, R8: 22; 0603
R7: 1K; 0603
R10: 1K5; 0603
R11: 10K; 0603
SWCLK: TPTP10R; TP10R
SWDIO: TPTP10R; TP10R
U1: LDO-3.3V; SOT23-5
X1: USB-CU09SAM; CU09SAM
X2: USB-SMD; USB-MINIB

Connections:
#RESET: JP2.4, R4.1
#RESETR: IC1.11 (PA1), R4.2
D+: C6.1, IC1.33 (PA12), R8.2
D-: C7.1, IC1.32 (PA11), R6.2
GND: C3.2, C5.2, C6.2, C7.2, C8.2, C9.1, C10.2, C11.2, C12.2, C13.2, D1.1 (GND), IC1.8 (VSSA), IC1.23 (VSS_1), IC1.35 (VSS_2), IC1.47 (VSS_3), J1.GND, JP1.1, JP1.3, JP2.2, LED2.C, R11.2, R14.1, U1.2 (GND), X1.5 (GND), X2.GND
unnamed: LED1.A, R7.2
unnamed: D1.4 (D3), J1.D+, R8.1, X1.3 (D+), X2.D+
unnamed: IC1.10 (PA0), LED1.C
unnamed: D1.3 (D2), J1.D-, R6.1, X1.2 (D-), X2.D-
unnamed: IC1.30 (PA9), R9.2
unnamed: IC1.31 (PA10), R12.2
unnamed: LED2.A, R10.1
unnamed: C3.1, C8.1, F1.2, U1.1 (IN), U1.3 (EN)
unnamed: IC1.44 (BOOT0), J2.1, R14.2
unnamed: C13.1, R11.1, X1.GND@1 (GND), X1.GND@2 (GND), X1.GND@3 (GND), X1.GND@4 (GND), X2.GND@1 (GND), X2.GND@2 (GND), X2.GND@3 (GND), X2.GND@4 (GND)
NRST: C5.1, IC1.7 (NRST), NRST.TP
RX: JP1.5, R12.1, R13.1
SWCLK: JP2.1, R1.1
SWCLKR: IC1.12 (PA2), R1.2
SWC_OB: IC1.37 (PA14), SWCLK.TP
SWDIO: JP2.3, R2.1
SWDIOR: IC1.14 (PA4), R2.2
SWD_OB: IC1.34 (PA13), SWDIO.TP
SWO/TDO: JP2.5, R3.1
SWOR: IC1.13 (PA3), R3.2, R5.1
TX: JP1.4, R9.1
VBUS: D1.2 (D1), F1.1, J1.VUSB (VBUS), R10.2, X1.1 (VBUS), X2.VBUS
VDD: C9.2, C10.1, C11.1, C12.1, IC1.1 (VBAT), IC1.9 (VDDA), IC1.24 (VDD_1), IC1.36 (VDD_2), IC1.48 (VDD_3), J2.2, JP1.2, R5.2, R7.1, R13.2, U1.5 (OUT)

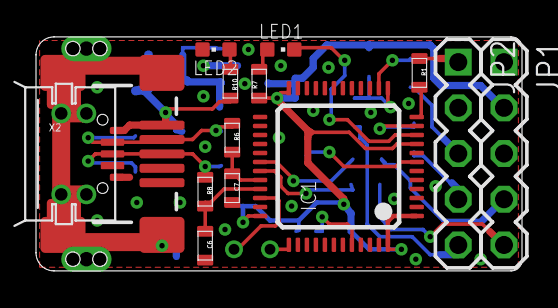
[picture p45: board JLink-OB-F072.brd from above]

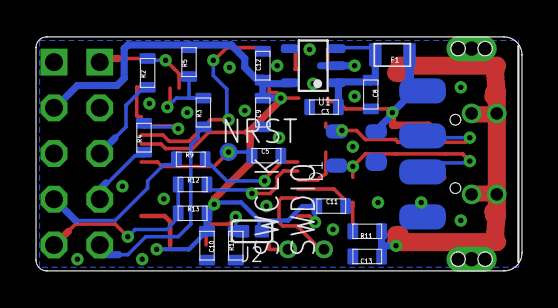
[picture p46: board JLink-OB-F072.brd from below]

Board: 2 copper layers, 27.0 x 13.0 mm, 39 parts (25 on the bottom side), 28 nets.

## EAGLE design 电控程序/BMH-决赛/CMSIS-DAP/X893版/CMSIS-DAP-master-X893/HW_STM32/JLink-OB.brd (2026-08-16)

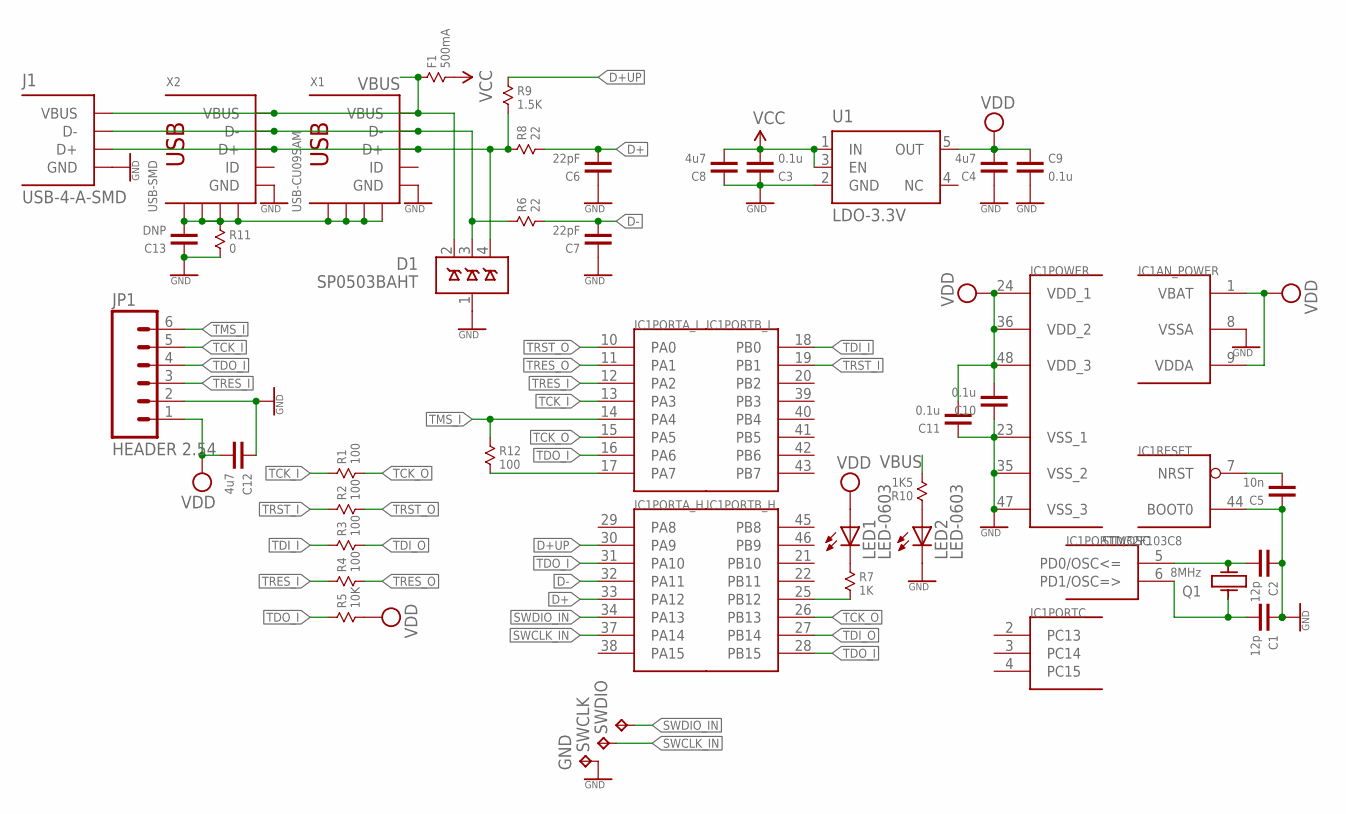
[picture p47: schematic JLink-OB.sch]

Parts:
C1, C2: 12p; 0603
C3, C9, C10, C11: 0.1u; 0603
C4, C8, C12: 4u7; 0603
C5: 10n; 0603
C6, C7: 22pF; 0603
C13: DNP; 0603
D1: SP0503BAHT; SOT143
F1: 500mA; 0805
GND: TPTP12R; TP12R
IC1: STM32F103C8; TQFP48
J1: USB-4-A-SMD; USB-A-SMD
JP1: HEADER 2.54; 1X06
LED1, LED2: LED-0603; CHIPLED_0603
Q1: 8MHz; KX-9A
R1, R2, R3, R4, R12: 100; 0603
R5: 10K; 0603
R6, R8: 22; 0603
R7: 1K; 0603
R9: 1.5K; 0603
R10: 1K5; 0603
R11: 0; 0603
SWCLK: TPTP12R; TP12R
SWDIO: TPTP12R; TP12R
U1: LDO-3.3V; SOT23-5
X1: USB-CU09SAM; CU09SAM
X2: USB-SMD; USB-MINIB

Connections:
D+: C6.1, IC1.33 (PA12), R8.2
D+UP: IC1.30 (PA9), R9.1
D-: C7.1, IC1.32 (PA11), R6.2
GND: C1.2, C2.2, C3.2, C4.2, C5.2, C6.2, C7.2, C8.2, C9.1, C10.2, C11.2, C12.2, C13.2, D1.1 (GND), GND.TP, IC1.8 (VSSA), IC1.23 (VSS_1), IC1.35 (VSS_2), IC1.44 (BOOT0), IC1.47 (VSS_3), J1.GND, JP1.2, LED2.C, R11.2, U1.2 (GND), X1.5 (GND), X2.GND
unnamed: C5.1, IC1.7 (NRST)
unnamed: D1.4 (D3), J1.D+, R8.1, R9.2, X1.3 (D+), X2.D+
unnamed: IC1.25 (PB12), R7.2
unnamed: D1.3 (D2), J1.D-, R6.1, X1.2 (D-), X2.D-
unnamed: C2.1, IC1.5 (PD0/OSC<=), Q1.3 (2)
unnamed: C1.1, IC1.6 (PD1/OSC=>), Q1.1
unnamed: LED2.A, R10.1
unnamed: LED1.C, R7.1
unnamed: C13.1, R11.1, X1.GND@1 (GND), X1.GND@2 (GND), X1.GND@3 (GND), X1.GND@4 (GND), X2.GND@1 (GND), X2.GND@2 (GND), X2.GND@3 (GND), X2.GND@4 (GND)
SWCLK_IN: IC1.37 (PA14), SWCLK.TP
SWDIO_IN: IC1.34 (PA13), SWDIO.TP
TCK_I: IC1.13 (PA3), JP1.5, R1.1
TCK_O: IC1.15 (PA5), IC1.26 (PB13), R1.2
TDI_I: IC1.18 (PB0), R3.1
TDI_O: IC1.27 (PB14), R3.2
TDO_I: IC1.16 (PA6), IC1.28 (PB15), IC1.31 (PA10), JP1.4, R5.1
TMS_I: IC1.14 (PA4), JP1.6, R12.1
TMS_O: IC1.17 (PA7), R12.2
TRES_I: IC1.12 (PA2), JP1.3, R4.1
TRES_O: IC1.11 (PA1), R4.2
TRST_I: IC1.19 (PB1), R2.1
TRST_O: IC1.10 (PA0), R2.2
VBUS: D1.2 (D1), F1.1, J1.VUSB (VBUS), R10.2, X1.1 (VBUS), X2.VBUS
VCC: C3.1, C8.1, F1.2, U1.1 (IN), U1.3 (EN)
VDD: C4.1, C9.2, C10.1, C11.1, C12.1, IC1.1 (VBAT), IC1.9 (VDDA), IC1.24 (VDD_1), IC1.36 (VDD_2), IC1.48 (VDD_3), JP1.1, LED1.A, R5.2, U1.5 (OUT)

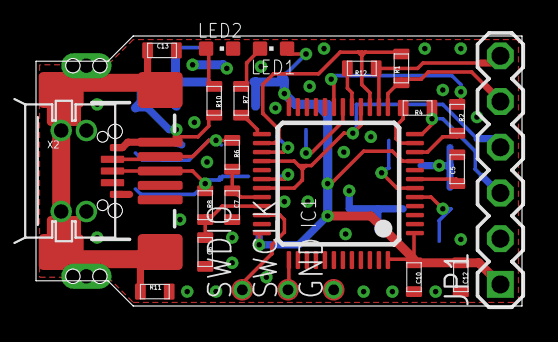
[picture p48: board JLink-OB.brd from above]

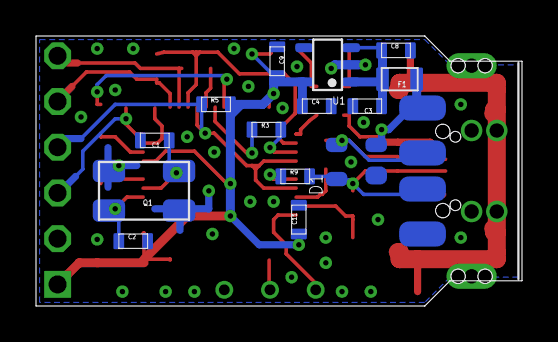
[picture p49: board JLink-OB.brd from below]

Board: 2 copper layers, 27.0 x 15.0 mm, 39 parts (15 on the bottom side), 29 nets.

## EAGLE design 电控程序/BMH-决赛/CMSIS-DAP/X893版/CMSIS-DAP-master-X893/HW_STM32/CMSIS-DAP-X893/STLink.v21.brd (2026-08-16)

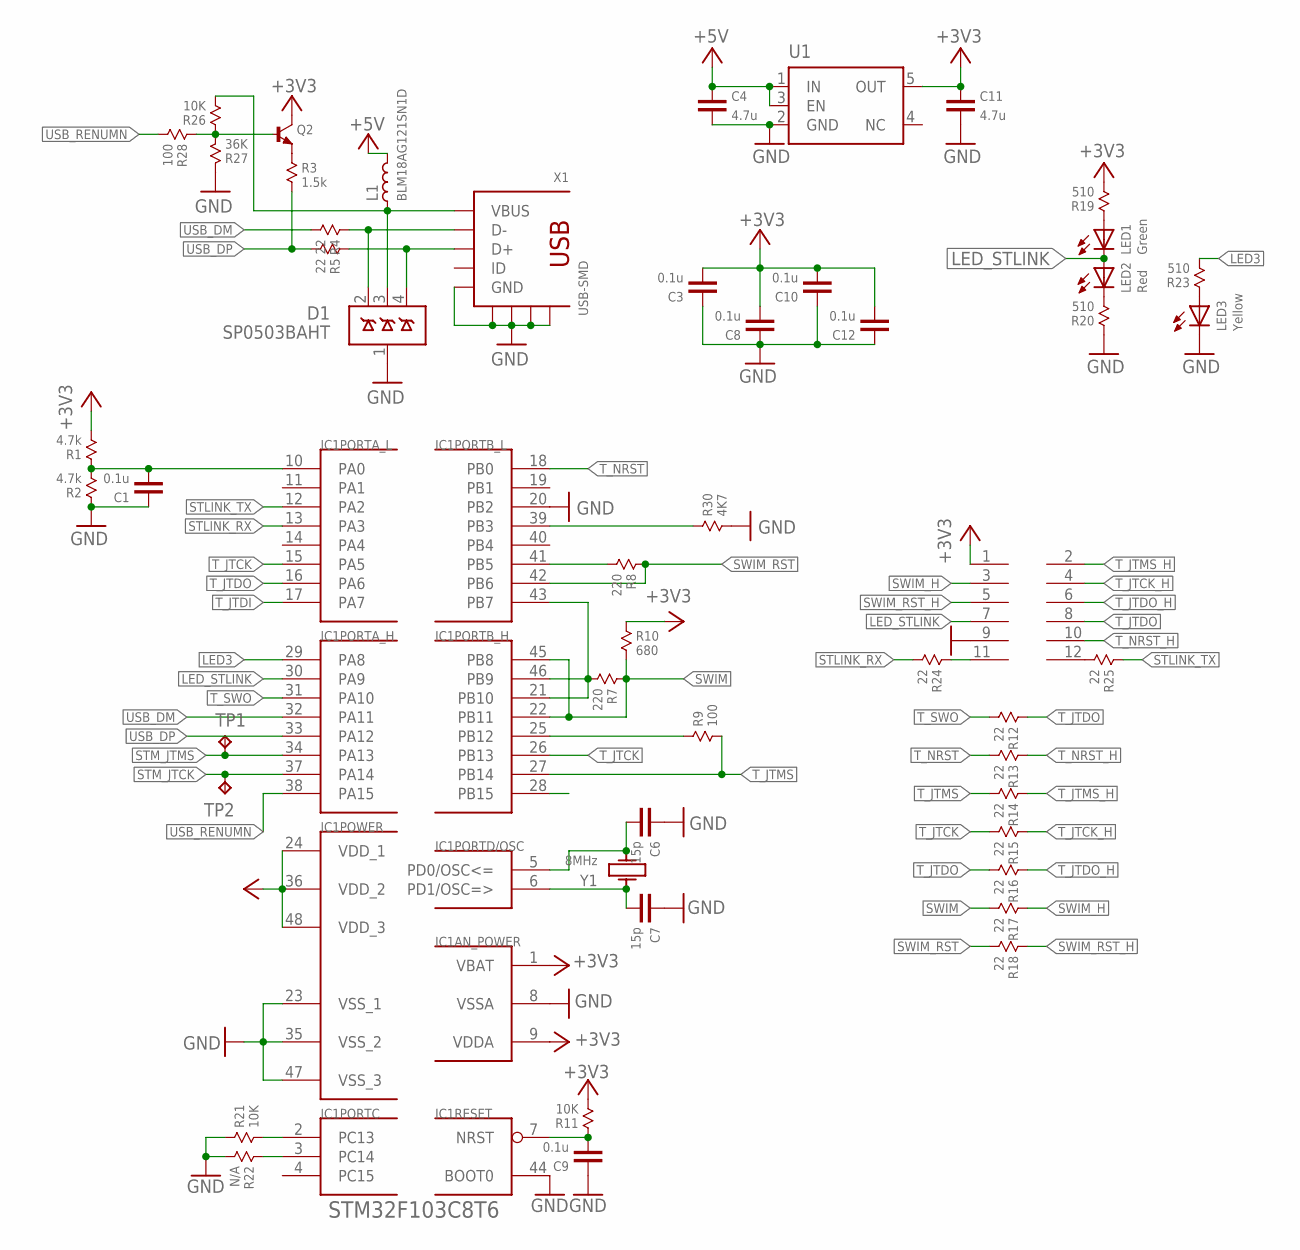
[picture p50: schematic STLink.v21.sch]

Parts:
C1, C3, C8, C9, C10, C12: 0.1u; 0603
C4, C11: 4.7u; 0603
C6, C7: 15p; 0603
CN2: M06X2; PLANAR-6X2
D1: SP0503BAHT; SOT143
IC1: STM32F103C8T6; TQFP48
L1: BLM18AG121SN1D; 0603
LED1: Green; CHIP-LED0603
LED2: Red; CHIP-LED0603
LED3: Yellow; CHIP-LED0603
Q2: NPNBC847; SOT-23
R1, R2: 4.7k; 0603
R3: 1.5k; 0603
R4, R5, R12, R13, R14, R15, R16, R17, R18, R24, R25: 22; 0603
R7, R8: 220; 0603
R9, R28: 100; 0603
R10: 680; 0603
R11, R21, R26: 10K; 0603
R19, R20, R23: 510; 0603
R22: N/A; 0603
R27: 36K; 0603
R30: 4K7; 0603
TP1, TP2: TPTP10R; TP10R
U1: TPS73033; SOT23-5
X1: USB-SMD; USB-MINIB
Y1: 8MHz; C0532

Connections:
+3V3: C3.1, C8.1, C10.1, C11.2, C12.1, CN2.1, IC1.1 (VBAT), IC1.9 (VDDA), IC1.24 (VDD_1), IC1.36 (VDD_2), IC1.48 (VDD_3), Q2.3 (C), R1.2, R10.1, R11.2, R19.2, U1.5 (OUT)
+5V: C4.2, L1.2, U1.1 (IN), U1.3 (EN)
AIN1: C1.1, IC1.10 (PA0), R1.1, R2.2
GND: C1.2, C3.2, C4.1, C6.2, C7.2, C8.2, C9.2, C10.2, C11.1, C12.2, CN2.9, D1.1 (GND), IC1.8 (VSSA), IC1.20 (PB2), IC1.23 (VSS_1), IC1.35 (VSS_2), IC1.44 (BOOT0), IC1.47 (VSS_3), LED3.C, R2.1, R20.1, R21.1, R22.2, R27.1, R30.2, U1.2 (GND), X1.GND, X1.GND@1 (GND), X1.GND@2 (GND), X1.GND@3 (GND), X1.GND@4 (GND)
LED3: IC1.29 (PA8), R23.2
LED_STLINK: CN2.7, IC1.30 (PA9), LED1.C, LED2.A
unnamed: C6.1, IC1.5 (PD0/OSC<=), Y1.3 (2)
unnamed: C7.1, IC1.6 (PD1/OSC=>), Y1.1
unnamed: C9.1, IC1.7 (NRST), R11.1
unnamed: IC1.39 (PB3), R30.1
unnamed: D1.2 (D1), R4.1, X1.D-
unnamed: D1.4 (D3), R5.1, X1.D+
unnamed: LED2.C, R20.2
unnamed: LED1.A, R19.1
unnamed: D1.3 (D2), L1.1, R26.2, X1.VBUS
unnamed: CN2.11, R24.1
unnamed: CN2.12, R25.2
unnamed: LED3.A, R23.1
unnamed: Q2.2 (E), R3.1
unnamed: IC1.2 (PC13), R21.2
unnamed: IC1.3 (PC14), R22.1
unnamed: Q2.1 (B), R26.1, R27.2, R28.1
STLINK_RX: IC1.13 (PA3), R24.2
STLINK_TX: IC1.12 (PA2), R25.1
STM_JTCK: IC1.37 (PA14), TP2.TP
STM_JTMS: IC1.34 (PA13), TP1.TP
SWIM: IC1.22 (PB11), IC1.45 (PB8), R7.1, R10.2, R17.2
SWIM_H: CN2.3, R17.1
SWIM_IN: IC1.21 (PB10), IC1.43 (PB7), IC1.46 (PB9), R7.2
SWIM_RST: IC1.42 (PB6), R8.1, R18.2
SWIM_RST_H: CN2.5, R18.1
SWIM_RST_IN: IC1.41 (PB5), R8.2
T_JTCK: IC1.15 (PA5), IC1.26 (PB13), R15.2
T_JTCK_H: CN2.4, R15.1
T_JTDI: IC1.17 (PA7)
T_JTDO: CN2.8, IC1.16 (PA6), R12.1, R16.2
T_JTDO_H: CN2.6, R16.1
T_JTMS: IC1.27 (PB14), R9.2, R14.2
T_JTMS_H: CN2.2, R14.1
T_NRST: IC1.18 (PB0), R13.2
T_NRST_H: CN2.10, R13.1
T_SWDIO_IN: IC1.25 (PB12), R9.1
T_SWO: IC1.31 (PA10), R12.2
USB_DM: IC1.32 (PA11), R4.2
USB_DP: IC1.33 (PA12), R3.2, R5.2
USB_RENUMN: IC1.38 (PA15), R28.2

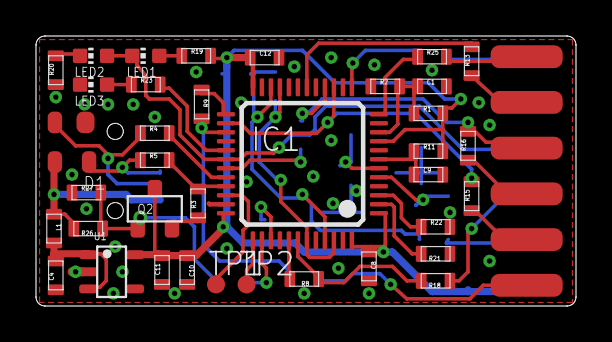
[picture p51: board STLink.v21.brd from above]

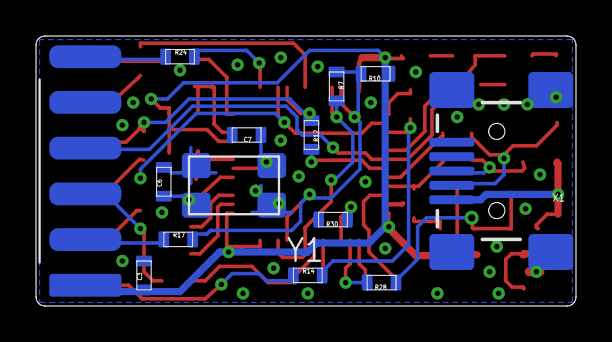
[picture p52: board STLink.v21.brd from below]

Board: 2 copper layers, 30.0 x 15.0 mm, 51 parts (14 on the bottom side), 45 nets.

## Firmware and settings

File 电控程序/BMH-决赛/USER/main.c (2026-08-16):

#include "stm32f4xx.h"
#include "usart.h"
#include "delay.h"
#include "board.h"
#include "Emm_V5.h"
#include "uart6_ckp.h"
#include "Serial.h"
#include "yyb_move.h"
#include "imu.h"
#include "PWM.h"
#include "LED.h"
#include "OLED.h"
#include "swith.h"
#include "pid.h"
#include "usart5.h"
#include "wit_c_sdk.h"
#include "exti.h"
#include "car.h"

void chusai(void);
void car_StartToPlate(void);
void car_StartToPlate_no(void);
void car_Start(void);
void car_ScanQR(void);
void car_GetWuLiao(void);
void car_GetWuLiao1(void);
void car_PlateToSeHuan1(void);
void car_SeHuan1Process(uint8_t TaskNum);
void car_SeHuan1ToSeHuan2(uint8_t TaskNum);

void car_SeHuan2ToPlate(void);
void car_Maduo(void);
void car_GoHome(void);
void car_ScanQR_test(void);
void set_shehuan(void);
void set_maduo(void);
void set_map(int a, int b);
void set_yuanpan(void); 

void car_SeHuan2Process(void);
void car_ScanQR_juesai(void);
void car_GetWuLiao_juesai(uint8_t TaskNum);
void car_SeHuan1ToSeHuan2_juesai(uint8_t TaskNum);
void car_SeHuan2ToPlate_juesai(uint8_t TaskNum);
void car_PlateToSehuan1_juesai(void);
void car_SeHuan2Process_juesai(uint8_t TaskNum);
void car_fangWuLiao_juesai(uint8_t TaskNum);
void car_GoHome_juesai(void);

void car_yuanliao_juesai(void);

//初赛所有的步骤都封装在里面了，直接在main里调用就行了
void chusai(void)
{
	/*====================初始化====================*/
	car_Init();
	
	/*====================启动====================*/
	car_StartToPlate();
	
	/*====================扫描二维码====================*/	
	car_ScanQR();
	
	/*====================第一次抓取物料====================*/
	car_GetWuLiao();
	
	/*====================第一次物料盘到粗加工====================*/
	car_PlateToSeHuan1();
	
	/*====================第一次粗加工====================*/
	car_SeHuan1Process(0);
	
	/*====================第一次粗加工到成品====================*/

	car_SeHuan1ToSeHuan2(0);
	
	/*====================第一次成品====================*/
	car_SeHuan2Process();
	
	/*====================成品到物料盘====================*/
	car_SeHuan2ToPlate();
	
	/*====================第二次抓取物料====================*/
	car_GetWuLiao1();
	
	/*====================第二次物料盘到粗加工====================*/
	car_PlateToSeHuan1();
	
	/*====================第二次粗加工====================*/
	car_SeHuan1Process(1);
	
	/*====================第二次粗加工到成品====================*/
	car_SeHuan1ToSeHuan2(1);
	
	/*====================第二次成品(码垛)====================*/
	car_Maduo();
	
	/*====================回家====================*/
	car_GoHome();
}

void juesai(void)
{
	/*====================初始化====================*/
	car_Init();
	
	/*====================启动====================*/
	car_StartToPlate(); //派+按键
	
	/*====================扫描二维码====================*/	
	car_ScanQR_juesai(); //移动到二维码，再移动到原料区
	
	/*====================第一次抓取物料====================*/
//	car_GetWuLiao_juesai(0);//码垛的识别+拿
	car_yuanliao_juesai();
	
	/*====================第一次物料环到粗加工环====================*/
	car_SeHuan1ToSeHuan2_juesai(0);
	
	
	/*====================第一次粗加工====================*/
	car_SeHuan2Process_juesai(0);
	
	/*====================第一次粗加工到成品====================*/
	car_SeHuan2ToPlate_juesai(0);
	
	
	/*====================第一次成品(到物料盘)====================*/
	car_fangWuLiao_juesai(0);
	
	/*====================成品到物料环====================*/
	car_PlateToSehuan1_juesai();
	
	/*====================第二次抓取物料====================*/
//	car_GetWuLiao_juesai(1);//码垛的识别+拿
	car_yuanliao_juesai();
	
	/*====================第二次物料环到粗加工环====================*/
	car_SeHuan1ToSeHuan2_juesai(1);
	
	/*====================第二次粗加工====================*/
	car_SeHuan2Process_juesai(1);
	
	/*====================第二次粗加工到成品====================*/
	car_SeHuan2ToPlate_juesai(1);
	
	/*====================第二次成品====================*/
	car_fangWuLiao_juesai(1);
	
	/*====================回家====================*/
	car_GoHome_juesai();
}


int main(void)
{		
	/*===================初赛一键启动====================*/	
//	chusai();
juesai();
	/*===================初赛一键启动====================*/

	
	/*====================调参数====================*/
//	set_yuanpan(); //设置色环：原地扫码、定位、拿色环
//	set_shehuan(); //设置色环：原地扫码、定位、放置色环
//	set_maduo(); //设置码垛，原地扫码、定位、放置色环
//	set_map(0,3); //跑图地图
	
	/*====================自定义调参====================*/
	
	car_Init();
	car_StartToPlate();		//派+按钮
	
	car_ScanQR_test();
	move_all(-70.0f,1000,200   ,0,1000,200   ,247,13);
	car_fangWuLiao_juesai(1);
//	car_yuanliao_juesai();
	jixie_reset();
	car_StartToPlate_no();	//按钮
	yuantai_fang0();
////	float zhuanpan0[3]={-71.0f , 20.0f , 247.0f};//转盘一号位
//float zhuanpan2[3]={90.0f  , 20.0f , 267.0f};//转盘二号位
	move_all(98.0f,1000,200   ,0,1000,200   ,267.5f,13);
	jixie_reset();
	car_GoHome_juesai();
	
	//亮度设置
//	TIM_SetCompare1(TIM3,200);
	
	//二维码测试
//	car_ScanQR(); 		//扫完码会移动
//	car_ScanQR_test();	//扫完码不会移动

	//通信测试
//	Serial_GetRxFlag();Serial_SendByte(0x32);

	//机械臂测试
//	move_all(0.0f,1000,200   ,0,1000,200    ,247,13);//
//	move_all(0.0f,1000,200   ,0,1000,200    ,70,13);//

	//勾爪测试
//	set_zhuashou_Angle_kai(); 	//开勾爪
//	set_zhuashou_Angle_he();	//关勾爪
	
	//物块平台测试
//	set_wukuaipingtai(0x01); 	//开勾爪
//	set_wukuaipingtai(0x02); 	//开勾爪
//	set_wukuaipingtai(0x03); 	//开勾爪

	//升降测试
//	delay_ms1((int)shengjiang_control(0,2000,240));

	//自转测试,最后一个参数越大越精准，越慢
//	mypid.integral = 0;PID_move(0,0,0,1000,90,0);//在原地旋转
//	PID_move(0,0,0,1000,90,3);
//	PID_move(0,0,0,1000,90,4);

	//移动测试
//	car_move2(150,0,150,150); 	//向开关为正方向移动
//	car_move1(0,-530,150,200);	//向地瓜派为正方向移动
//	car_move2(-150,0,150,150); 	//向机械臂为正方向移动
//	car_move1(0,530,150,200);	//向物料盘为正方向移动

	//所以机构复位到起始位置
//	jixie_reset();

}












void car_yuanliao_juesai(void)
{
	while(1){
		wait_send_shumeipai(0x68,10000);	
		transfer_pi_position4(0x02);
		car_move_distance(direct_x,direct_y,180,150);//至此第一次定标完成
		delay_ms1(200);
		if(Serial_RxPacket[8] != 0x34){
			break;
		}
	}
//	PID_move(0,0,0,1000,0,4);
		PID_move(0,0,0,1000,-180,4);
	{
		wait_send_shumeipai(0x68,10000);		
		transfer_pi_position4(0x02);	
		if(Serial_RxPacket[8] == 0x34){
			car_move_distance(0,0,70,50);
		}else{	
			car_move_distance(direct_x,direct_y,180,150);//至此第二次定标完成
		}
	}
	
	/*====================第一次粗加工拿s====================*/
	
	wait_send_shumeipai(0x69,20000);
	ypcode[0]= Serial_RxPacket[0]-0x30;ypcode[1] = Serial_RxPacket[1]-0x30;ypcode[2] = Serial_RxPacket[2]-0x30;

	
	set_wukuaipingtai(0x01);
	//拿一
	set_zhuashou_Angle_kai();
	na(ypcode[0]);
	
	set_wukuaipingtai(0x02);
	//拿二
	na(ypcode[1]);
	set_wukuaipingtai(0x03);
	//拿三
	na(ypcode[2]);
	//复位到识别的位置
	set_wukuaipingtai(0x01);
	
	
	move_all(-70.0f,1000,200   ,0,1000,200    ,247,13);//近识别位
	/*====================第一次粗加工拿e====================*/

}


/*====================启动====================*/
void car_Start(void)
{
	while(swith_out() == 1){		
		LED_Toggle2();
		delay_ms1(50);
		// 简单方法：直接显示
		OLED_ShowString(12, 1, "OK");
	}//地瓜派已经准备好，按下开关即可启动
	mypid.integral = 0;
	WHT101_ANGLEZCali();//101z轴置零
}

void car_StartToPlate(void)
{
	while(1){
		LED_Toggle2();
		delay_ms1(500);
		// 简单方法：直接显示
		if((Serial_RxPacket[0]==0x39) && (Serial_RxPacket[1]==0x38)){
			break;
	    }
		
	}

	while(swith_out() == 1){		
		LED_Toggle2();
		delay_ms1(50);
		// 简单方法：直接显示
		OLED_ShowString(12, 1, "OK");
	}//地瓜派已经准备好，按下开关即可启动
	mypid.integral = 0;
	WHT101_ANGLEZCali();//101z轴置零
}

void car_StartToPlate_no(void)
{

	while(swith_out() == 1){		
		LED_Toggle2();
		delay_ms1(50);
		// 简单方法：直接显示
		OLED_ShowString(12, 1, "OK");
	}//地瓜派已经准备好，按下开关即可启动
	mypid.integral = 0;
	WHT101_ANGLEZCali();//101z轴置零
}

/*====================扫描二维====================*/	
void car_ScanQR_juesai(void)
{
		//扫二维码
	Serial_GetRxFlag();Serial_SendByte(0x31);
	map(0,1);
	//读取地瓜派信息	
	while(1){
		if (Serial_GetRxFlag() == 1){   //收到数据包
			   sprintf(tjcstr, "t0.txt=\"%d%d%d+%d%d%d \"",
										Serial_RxPacket[0]-0x30,Serial_RxPacket[1]-0x30,Serial_RxPacket[2]-0x30,
										Serial_RxPacket[4]-0x30,Serial_RxPacket[5]-0x30,Serial_RxPacket[6]-0x30);
				HMISends(tjcstr);
				HMISendb(0xff);//在显示屏上面显示任务
				break;
			  }
	}	
	task[0]= Serial_RxPacket[0]-0x30;task[1] = Serial_RxPacket[1]-0x30;task[2] = Serial_RxPacket[2]-0x30;
	task[3]= Serial_RxPacket[4]-0x30;task[4] = Serial_RxPacket[5]-0x30;task[5] = Serial_RxPacket[6]-0x30;
	
	set_zhuashou_Angle(40.0f,300);
	move_all(-70.0f,1000,200   ,0,1000,200   ,247,13);
	
	map(1,5);
	TIM_SetCompare1(TIM3,200);
//	Serial_GetRxFlag();Serial_SendByte(0x39);
}

void car_ScanQR(void)
{
		//扫二维码
	Serial_GetRxFlag();Serial_SendByte(0x31);
	//移动到地图正上方
	car_move2(150,0,150,150);
	car_move1(0,-1035,150,200);
	//读取地瓜派信息	
	while(1){
		if (Serial_GetRxFlag() == 1){   //收到数据包
			   sprintf(tjcstr, "t0.txt=\"%d%d%d+%d%d%d \"",
										Serial_RxPacket[0]-0x30,Serial_RxPacket[1]-0x30,Serial_RxPacket[2]-0x30,
										Serial_RxPacket[4]-0x30,Serial_RxPacket[5]-0x30,Serial_RxPacket[6]-0x30);
				HMISends(tjcstr);
				HMISendb(0xff);//在显示屏上面显示任务
				break;
			  }
	}	
	task[0]= Serial_RxPacket[0]-0x30;task[1] = Serial_RxPacket[1]-0x30;task[2] = Serial_RxPacket[2]-0x30;
	task[3]= Serial_RxPacket[4]-0x30;task[4] = Serial_RxPacket[5]-0x30;task[5] = Serial_RxPacket[6]-0x30;
	
	set_zhuashou_Angle(40.0f,300);
	move_all(-70.0f,1000,200   ,0,1000,200   ,247,13);
	
	TIM_SetCompare1(TIM3,200);

	car_move1(0,-1000+100,150,200);
	car_move2(-10,0,100,100);
	Serial_GetRxFlag();Serial_SendByte(0x32);
	move_all(85.0f,1000,200   ,0,1000,200   ,247,13);
}

void car_ScanQR_test(void)
{
		//扫二维码
	Serial_GetRxFlag();Serial_SendByte(0x31);
//	car_move2(150,0,150,150);
//	car_move1(0,-530,150,200);
	//读取地瓜派信息	
	while(1){
		if (Serial_GetRxFlag() == 1){   //收到数据包
			   sprintf(tjcstr, "t0.txt=\"%d%d%d+%d%d%d \"",
										Serial_RxPacket[0]-0x30,Serial_RxPacket[1]-0x30,Serial_RxPacket[2]-0x30,
										Serial_RxPacket[4]-0x30,Serial_RxPacket[5]-0x30,Serial_RxPacket[6]-0x30);
				HMISends(tjcstr);
				HMISendb(0xff);//在显示屏上面显示任务
				break;
			  }
	}	
	task[0]= Serial_RxPacket[0]-0x30;task[1] = Serial_RxPacket[1]-0x30;task[2] = Serial_RxPacket[2]-0x30;
	task[3]= Serial_RxPacket[4]-0x30;task[4] = Serial_RxPacket[5]-0x30;task[5] = Serial_RxPacket[6]-0x30;
	
	set_zhuashou_Angle(40.0f,300);

	
	TIM_SetCompare1(TIM3,200);
//	car_move1(0,-1000+90,150,200);

}

void car_GetWuLiao(void)
{
	while(1){
		while(1){
			if(Serial_GetRxFlag() == 1){
				break;
			}
		}
		transfer_pi_position2();
		car_move_distance(direct_x,direct_y,100,80);//至此第一次定标完成
		wait_send_shumeipai(0x32,15000);

		if(Serial_RxPacket[8] != 0x34){
			break;
		}else{
			wait_send_shumeipai(0x32,15000);
		}	
	}
	
	wait_send_shumeipai(0x33,20000);
	ypcode[0]= Serial_RxPacket[0]-0x30;ypcode[1] = Serial_RxPacket[1]-0x30;ypcode[2] = Serial_RxPacket[2]-0x30;
	
	//拿走第一个物块
	yuantai_na(ypcode[0]);
	move_all(0.0f,1000,200   ,0,1000,200  ,70,12);

	set_wukuaipingtai_Angle(20.0f+124.0f,300);
	

	//拿走第二个物块
	yuantai_na1(ypcode[1]);

	wait_send_shumeipai(0x35,30000);
	while(1){
		if(Serial_RxPacket[0] == 0x39 && Serial_RxPacket[1] == 0x38){
			break;
		}
	}Serial_RxPacket[0] = 0x30;Serial_RxPacket[1] = 0x30;
	
	yuantai_na2(ypcode[1]);
	set_wukuaipingtai(0x03);
	
	//拿走第三个物块
	yuantai_na1(ypcode[2]); 
	
	wait_send_shumeipai(0x36,30000);
	while(1){
		if(Serial_RxPacket[0] == 0x39 && Serial_RxPacket[1] == 0x38){
			break;
		}
	}Serial_RxPacket[0] = 0x30;Serial_RxPacket[1] = 0x30;	
	
	yuantai_na2(ypcode[2]);

	TIM_SetCompare1(TIM3,0);
	//复位到识别的位置
	set_zhuashou_Angle(45.0f,200);
	move_all(-70.0f,1000,200   ,0,1000,200    ,247,13);//转过来识别
	set_wukuaipingtai(0x01);
	
}

void car_GetWuLiao1(void)
{
	while(1){
		while(1){
			if(Serial_GetRxFlag() == 1){
				break;
			}
		}
		transfer_pi_position2();
		car_move_distance(direct_x,direct_y,100,80);//至此第一次定标完成
		wait_send_shumeipai(0x32,15000);

		if(Serial_RxPacket[8] != 0x34){
			break;
		}else{
			wait_send_shumeipai(0x61,15000);
		}	
	}

	move_all(85.0f,1000,200   ,0,1000,200   ,244,10);
	wait_send_shumeipai(0x34,20000);
	ypcode[0]= Serial_RxPacket[0]-0x30;ypcode[1] = Serial_RxPacket[1]-0x30;ypcode[2] = Serial_RxPacket[2]-0x30;
	
	//拿走第一个物块
	yuantai_na(ypcode[0]);
	move_all(0.0f,1000,200   ,0,1000,200   ,70,13);
	set_wukuaipingtai_Angle(20.0f+124.0f,300);
	

	//拿走第二个物块
	yuantai_na1(ypcode[1]);

	wait_send_shumeipai(0x62,30000);
	while(1){
		if(Serial_RxPacket[0] == 0x39 && Serial_RxPacket[1] == 0x38){
			break;
		}
	}Serial_RxPacket[0] = 0x30;Serial_RxPacket[1] = 0x30;
	
	yuantai_na2(ypcode[1]);
	set_wukuaipingtai(0x03);
	
	//拿走第三个物块
	yuantai_na1(ypcode[2]); 
	
	wait_send_shumeipai(0x63,30000);
	while(1){
		if(Serial_RxPacket[0] == 0x39 && Serial_RxPacket[1] == 0x38){
			break;
		}
	}Serial_RxPacket[0] = 0x30;Serial_RxPacket[1] = 0x30;	
	
	yuantai_na2(ypcode[2]);

	TIM_SetCompare1(TIM3,0);
	//复位到识别的位置
	
	set_zhuashou_Angle(45.0f,200);
	move_all(-70.0f,1000,200   ,0,1000,200    ,247,13);//转过来识别
	set_wukuaipingtai(0x01);
	
}

//决赛放物块到转盘上
void car_fangWuLiao_juesai(uint8_t TaskNum)
{
	if(TaskNum ==0){
			Serial_GetRxFlag();Serial_SendByte(0x32);
		}else if(TaskNum ==1){
			Serial_GetRxFlag();Serial_SendByte(0x61);
		}
	
	while(1){
		while(1){
			if(Serial_GetRxFlag() == 1){
				break;
			}
		}
		transfer_pi_position2();
		car_move_distance(direct_x,direct_y,100,80);//至此第一次定标完成

		
		if(Serial_RxPacket[8] != 0x34){
			break;
		}else{
			if(TaskNum ==0){
			Serial_GetRxFlag();Serial_SendByte(0x32);
			}else{
			Serial_GetRxFlag();Serial_SendByte(0x61);
		}
		}	
	}
	
	//定位之后先拿一个物块在手上，之后看顺序
	yuantai_fang0();
//	move_all(85.0f,1000,200   ,0,1000,200   ,244,10);
	if(TaskNum ==0){
			wait_send_shumeipai(0x33,15000);
		}else if(TaskNum ==1){
			wait_send_shumeipai(0x34,15000);
		}
	
	ypcode[0]= Serial_RxPacket[0]-0x30;ypcode[1] = Serial_RxPacket[1]-0x30;ypcode[2] = Serial_RxPacket[2]-0x30;
	
	//拿走第一个物块
	yuantai_fang(ypcode[0]);
	set_wukuaipingtai_Angle(20.0f+124.0f,300);
	

	//拿走第二个物块
	yuantai_fang1(ypcode[1]);

	if(TaskNum ==0){
			wait_send_shumeipai(0x35,15000);
		}else if(TaskNum ==1){
			wait_send_shumeipai(0x62,15000);
		}
	
	while(1){
		if(Serial_RxPacket[0] == 0x39 && Serial_RxPacket[1] == 0x38){
			break;
		}
	}Serial_RxPacket[0] = 0x30;Serial_RxPacket[1] = 0x30;
	
	yuantai_fang2(ypcode[1]);
	set_wukuaipingtai(0x03);
	
	//拿走第三个物块
	yuantai_fang1(ypcode[2]); 
	
	if(TaskNum ==0){
			wait_send_shumeipai(0x36,15000);
		}else if(TaskNum ==1){
			wait_send_shumeipai(0x63,15000);
		}
	while(1){
		if(Serial_RxPacket[0] == 0x39 && Serial_RxPacket[1] == 0x38){
			break;
		}
	}Serial_RxPacket[0] = 0x30;Serial_RxPacket[1] = 0x30;	
	
	yuantai_fang2(ypcode[2]);

	TIM_SetCompare1(TIM3,0);
	//复位到识别的位置
	set_zhuashou_Angle(45.0f,200);
	move_all(-70.0f,1000,200   ,0,1000,200    ,247,13);//转过来识别
	set_wukuaipingtai(0x01);
	
}

void car_PlateToSeHuan1(void)
{
			//到粗加工区
	PID_move(-30,0,0,400,0,1);//回倒车
	delay_ms1(200);
	car_move1(0,400,150,200);
	
	mypid.integral = 0;PID_move(0,0,0,1000,90,0);//在原地旋转
	PID_move(0,0,0,1000,90,3);
	
	car_move1(0,-1700,200,200);//快速通过
	
	mypid.integral = 0;PID_move(0,0,0,1000,-180,0);//在粗加工区原地旋转
	TIM_SetCompare1(TIM3,500);  //关闭补光灯
	PID_move(0,0,0,1000,-180,3);
	
}

void car_SeHuan1Process(uint8_t TaskNum)
{
	/*====================第一次粗加工s====================*/
	move_all(-70.0f,1000,200   ,0,1000,200    ,247,13);//转过来识别
	
	while(1){
		wait_send_shumeipai(0x37,10000);//如果发送了信息，但是一直没有得到回应，那么就一直发送
		transfer_pi_position11(0x02);
		car_move_distance(direct_x,direct_y,180,150);
		if(Serial_RxPacket[8] != 0x34){
			break;
		}
		//如果返回了没看到的信息，那就微微调整一下，再重复给地瓜派发送
		//反之如果返回了看到的信息（也即第九位并非0x34）,则可以退出该程序
	}

	//角度校正
//	PID_move(0,0,0,1000,0.0f,4);//-180.0改为0
	PID_move(0,0,0,1000,-180.0f,4);//-180.0改为0
	delay_ms1(500);
	
	
	//精细定标
	{
		wait_send_shumeipai(0x38,10000);//如果发送了信息，但是一直没有得到回应，那么就一直发送
		transfer_pi_position12(0x02);	
		if(Serial_RxPacket[8] == 0x34){
			car_move_distance(0,0,70,50);//如果没有看到颜色，那就不移动
		}else{	
			car_move_distance(direct_x,direct_y,130,100);//如果看到颜色，那就按照正常的方式移动
		}
	}//至此第二次定标完成
	
	
//*************************1.4.1Start第三部分，放**********************//
	set_zhuashou_Angle_kai();
	move_all(0.0f,1000,200   ,20,1000,200   ,70,13);//复位
	move_all(0.0f,1000,200   ,35,1000,200   ,70,13);//物块平台抓物块
	set_zhuashou_Angle_he();
	//放置第一个
	fangzhi(task[0+(TaskNum)*3]);

	set_wukuaipingtai_Angle(143.0f,300);
	delay_ms1((int)shengjiang_control(20,2000,240));
	move_all(0.0f,1000,200   ,20,1000,200   ,70,13);//复位
	move_all(0.0f,1000,200   ,35,1000,200   ,70,13);//物块平台抓物块
	set_zhuashou_Angle_he();
	
	//放置第二个	
	fangzhi(task[1+(TaskNum)*3]);
	
	set_wukuaipingtai_Angle(258.0f,300);
	delay_ms1((int)shengjiang_control(20,2000,240));
	move_all(0.0f,1000,200   ,20,1000,200   ,70,13);//复位
	move_all(0.0f,1000,200   ,35,1000,200   ,70,13);//物块平台抓物块
	set_zhuashou_Angle_he();
	
	//放置第三个	
	fangzhi(task[2+(TaskNum)*3]);
	//复位到识别的位置
	set_wukuaipingtai(0x01);
	set_zhuashou_Angle_kai();
	/*====================第一次粗加工放e====================*/


	/*====================第一次粗加工拿s====================*/
	delay_ms1((int)shengjiang_control(70,2000,240));//复位
	
	
	
	set_wukuaipingtai(0x01);
	//拿一
	set_zhuashou_Angle_kai();
	na(task[0+(TaskNum)*3]);
	
	set_wukuaipingtai_Angle(143.0f,300);
	//拿二
	na(task[1+(TaskNum)*3]);
	set_wukuaipingtai_Angle(258.0f,300);
	//拿三
	na(task[2+(TaskNum)*3]);
	//复位到识别的位置
	set_wukuaipingtai(0x01);
	
	move_all(-70.0f,1000,200   ,0,1000,200    ,247,13);//转过来识别
	/*====================第一次粗加工拿e====================*/
	/*====================第一次粗加工e====================*/
}

void car_SeHuan2Process_juesai(uint8_t TaskNum)
{
	/*====================第一次粗加工s====================*/
	move_all(-70.0f,1000,200   ,0,1000,200    ,247,13);//转过来识别
	
	while(1){
		wait_send_shumeipai(0x37,10000);//如果发送了信息，但是一直没有得到回应，那么就一直发送
		transfer_pi_position11(0x02);
		car_move_distance(direct_x,direct_y,180,150);
		if(Serial_RxPacket[8] != 0x34){
			break;
		}
		//如果返回了没看到的信息，那就微微调整一下，再重复给地瓜派发送
		//反之如果返回了看到的信息（也即第九位并非0x34）,则可以退出该程序
	}

	//角度校正
//	PID_move(0,0,0,1000,0.0f,4);//-180.0改为0
	PID_move(0,0,0,1000,90.0f,4);
	delay_ms1(500);
	
	
	//精细定标
	{
		wait_send_shumeipai(0x38,10000);//如果发送了信息，但是一直没有得到回应，那么就一直发送
		transfer_pi_position12(0x02);	
		if(Serial_RxPacket[8] == 0x34){
			car_move_distance(0,0,70,50);//如果没有看到颜色，那就不移动
		}else{	
			car_move_distance(direct_x,direct_y,130,100);//如果看到颜色，那就按照正常的方式移动
		}
	}//至此第二次定标完成
	
	
//*************************1.4.1Start第三部分，放**********************//
	set_zhuashou_Angle_kai();
	move_all(0.0f,1000,200   ,20,1000,200   ,70,13);//复位
	move_all(0.0f,1000,200   ,35,1000,200   ,70,13);//物块平台抓物块
	set_zhuashou_Angle_he();
	//放置第一个
	fangzhi(task[0+(TaskNum)*3]);

	set_wukuaipingtai_Angle(143.0f,300);
	delay_ms1((int)shengjiang_control(20,2000,240));
	move_all(0.0f,1000,200   ,20,1000,200   ,70,13);//复位
	move_all(0.0f,1000,200   ,35,1000,200   ,70,13);//物块平台抓物块
	set_zhuashou_Angle_he();
	
	//放置第二个	
	fangzhi(task[1+(TaskNum)*3]);
	
	set_wukuaipingtai_Angle(258.0f,300);
	delay_ms1((int)shengjiang_control(20,2000,240));
	move_all(0.0f,1000,200   ,20,1000,200   ,70,13);//复位
	move_all(0.0f,1000,200   ,35,1000,200   ,70,13);//物块平台抓物块
	set_zhuashou_Angle_he();
	
	//放置第三个	
	fangzhi(task[2+(TaskNum)*3]);
	//复位到识别的位置
	set_wukuaipingtai(0x01);
	set_zhuashou_Angle_kai();
	/*====================第一次粗加工放e====================*/


	/*====================第一次粗加工拿s====================*/
	delay_ms1((int)shengjiang_control(70,2000,240));//复位
	
	
	
	set_wukuaipingtai(0x01);
	//拿一
	set_zhuashou_Angle_kai();
	na(task[0+(TaskNum)*3]);
	
	set_wukuaipingtai_Angle(143.0f,300);
	//拿二
	na(task[1+(TaskNum)*3]);
	set_wukuaipingtai_Angle(258.0f,300);
	//拿三
	na(task[2+(TaskNum)*3]);
	//复位到识别的位置
	set_wukuaipingtai(0x01);
	
	move_all(-70.0f,1000,200   ,0,1000,200    ,247,13);//转过来识别
	/*====================第一次粗加工拿e====================*/
	/*====================第一次粗加工e====================*/
}



void car_SeHuan1ToSeHuan2(uint8_t TaskNum)
{
	PID_move(-30,0,0,300,-180,1);//在粗加工区回退
	PID_move(0,0,0,500,-180,3);
	car_move1(140,140+680,180,180);//从绿色出发
	delay_ms1(100);
	
	mypid.integral = 0;PID_move(0,0,0,1000,90,0);

	
	car_move1(0,140+645,180,150);
	TIM_SetCompare1(TIM3,500);  //关闭补光灯
}

void car_SeHuan1ToSeHuan2_juesai(uint8_t TaskNum)
{
	PID_move(-30,0,0,300,-180,1);//在粗加工区回退
	PID_move(0,0,0,500,-180,3);
	car_move1(140,140+680,180,180);//从绿色出发
	delay_ms1(100);
	
	mypid.integral = 0;PID_move(0,0,0,1000,90,0);

	car_move1(0,140+645,180,150);
	TIM_SetCompare1(TIM3,300);  //关闭补光灯
}

void car_SeHuan2Process(void)
{
	while(1){
		wait_send_shumeipai(0x37,15000);
		transfer_pi_position11(0x02);
		car_move_distance(direct_x,direct_y,180,150);
		if(Serial_RxPacket[8] != 0x34){
			break;
		}
		//如果返回了没看到的信息，那就微微调整一下，再重复给地瓜派发送
		//反之如果返回了看到的信息（也即第九位并非0x34）,则可以退出该程序
	}

	//角度校正
	wait_send_shumeipai(0x64,10000);
	angle = (Serial_RxPacket[7]-0x30) + (Serial_RxPacket[8]-0x30)*0.1f;
	if(ABS(angle) >= 2.0f){
		angle = 2.0f;
	}
	if((Serial_RxPacket[6]-0x30) == 0){
		angle = -angle;
	}
	PID_move(0,0,0,1000,90-angle,4);
	
	//精细定标
	{
		wait_send_shumeipai(0x38,10000);//如果发送了信息，但是一直没有得到回应，那么就一直发送
		transfer_pi_position12(0x02);	
		if(Serial_RxPacket[8] == 0x34){
			car_move_distance(0,0,70,50);//如果没有看到颜色，那就不移动
		}else{	
			car_move_distance(direct_x,direct_y,130,100);//如果看到颜色，那就按照正常的方式移动
		}
	}//至此第二次定标完成

//*************************1.6.1Start第三部分，放**********************//
	set_zhuashou_Angle_kai();
	move_all(0.0f,1000,200   ,0,1000,200   ,70,13);//复位
	move_all(0.0f,1000,200   ,35,1000,200   ,70,13);//物块平台抓物块
	set_zhuashou_Angle_he();
	//放置第一个
	fangzhi(task[0]);
//	jixie_reset();
	set_wukuaipingtai_Angle(143.0f,300);
	delay_ms1((int)shengjiang_control(0,2000,240));
	move_all(0.0f,1000,200   ,0,1000,200   ,70,13);//复位
	move_all(0.0f,1000,200   ,35,1000,200   ,70,13);//物块平台抓物块
	set_zhuashou_Angle_he();
	
	//放置第二个	
	fangzhi(task[1]);
	
	set_wukuaipingtai_Angle(258.0f,300);
	delay_ms1((int)shengjiang_control(0,2000,240));
	move_all(0.0f,1000,200   ,0,1000,200   ,70,13);//复位
	move_all(0.0f,1000,200   ,35,1000,200   ,70,13);//物块平台抓物块
	set_zhuashou_Angle_he();
	
	//放置第三个	
	fangzhi(task[2]);
	//复位到识别的位置
	set_wukuaipingtai(0x01);
	set_zhuashou_Angle_kai();
	delay_ms1((int)shengjiang_control(0,2000,240));
	move_all(-30.0f,1000,200   ,0,1000,200    ,247,13);//转过来识别
}
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

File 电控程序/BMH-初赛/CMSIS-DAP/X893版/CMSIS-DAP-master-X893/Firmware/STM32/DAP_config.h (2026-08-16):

/**************************************************************************//**
 * @file     DAP_config.h
 * @brief    CMSIS-DAP Configuration File for STM32F103C6/8/B
 * @version  V1.00
 * @date     02. Oct 2012
 *
 * @note
 * Copyright (C) 2012 ARM Limited. All rights reserved.
 *
 * @par
 * ARM Limited (ARM) is supplying this software for use with Cortex-M
 * processor based microcontrollers.
 *
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
 ******************************************************************************/

#ifndef __DAP_CONFIG_H__
#define __DAP_CONFIG_H__

#include <stdio.h>
#include <stddef.h>
#include <stdint.h>

typedef const struct
{
	void	(* LedConnected)	(uint16_t);
	void	(* LedRunning)		(uint16_t);
} CoreDescriptor_t;

extern const CoreDescriptor_t * pCoreDescriptor;

typedef const struct
{
	void		(* UserInit)	(CoreDescriptor_t * core);
	uint32_t	(* UserProcess)	(uint8_t *, uint8_t *);
	void		(* UserAbort)	(void);
} UserAppDescriptor_t;

#if !defined ( BOARD_V1      )	\
 && !defined ( BOARD_V2      )	\
 && !defined ( STLINK_V20    )	\
 && !defined ( STLINK_V21    )	\
 && !defined ( BOARD_STM32RF )
	#error "Board undefined"
#endif

#if   defined( __GNUC__ )
	/*	With GCC/RAISONANCE, small printf (option LD Linker->Libraries->Small printf
		set to 'Yes') calls __io_putchar() */
	#define PUTCHAR_PROTOTYPE int __io_putchar(int ch)
#elif defined( __CC_ARM )
	#define PUTCHAR_PROTOTYPE int fputc(int ch, FILE *f)
#else
	#error "Unknown compiler"
#endif

#if   defined( USE_DEBUG )
	#define DEBUG(...)	printf(__VA_ARGS__)
	#define INFO(...)	printf(__VA_ARGS__)
	#define ERROR(...)	printf(__VA_ARGS__)
#elif defined( USE_INFO )
	#define DEBUG(...)
	#define INFO(...)	printf(__VA_ARGS__)
	#define ERROR(...)	printf(__VA_ARGS__)
#elif defined( USE_ERROR )
	#define DEBUG(...)
	#define INFO(...)
	#define ERROR(...)	printf(__VA_ARGS__)
#else
	#define DEBUG(...)
	#define INFO(...)
	#define ERROR(...)
#endif

//**************************************************************************************************
/** 
\defgroup DAP_Config_Debug_gr CMSIS-DAP Debug Unit Information
\ingroup DAP_ConfigIO_gr 
@{
Provides definitions about:
 - Definition of Cortex-M processor parameters used in CMSIS-DAP Debug Unit.
 - Debug Unit communication packet size.
 - Debug Access Port communication mode (JTAG or SWD).
 - Optional information about a connected Target Device (for Evaluation Boards).
*/

#include <stm32f10x.h>

/// Processor Clock of the Cortex-M MCU used in the Debug Unit.
/// This value is used to calculate the SWD/JTAG clock speed.
#define CPU_CLOCK				SystemCoreClock		///< Specifies the CPU Clock in Hz

/// Number of processor cycles for I/O Port write operations.
/// This value is used to calculate the SWD/JTAG clock speed that is generated with I/O
/// Port write operations in the Debug Unit by a Cortex-M MCU. Most Cortex-M processors
/// requrie 2 processor cycles for a I/O Port Write operation.  If the Debug Unit uses
/// a Cortex-M0+ processor with high-speed peripheral I/O only 1 processor cycle might be 
/// requrired.
#define IO_PORT_WRITE_CYCLES	2               ///< I/O Cycles: 2=default, 1=Cortex-M0+ fast I/0

/// Indicate that Serial Wire Debug (SWD) communication mode is available at the Debug Access Port.
/// This information is returned by the command \ref DAP_Info as part of <b>Capabilities</b>.
#define DAP_SWD                 1               ///< SWD Mode:  1 = available, 0 = not available

/// Indicate that JTAG communication mode is available at the Debug Port.
/// This information is returned by the command \ref DAP_Info as part of <b>Capabilities</b>.
#if defined ( BOARD_STM32RF )	\
 || defined ( STLINK_V20 )		\
 || defined ( STLINK_V21 )
	#define DAP_JTAG			0				///< JTAG Mode: 1 = available, 0 = not available.
#else
	#define DAP_JTAG			1				///< JTAG Mode: 1 = available, 0 = not available.
#endif

/// Configure maximum number of JTAG devices on the scan chain connected to the Debug Access Port.
/// This setting impacts the RAM requirements of the Debug Unit. Valid range is 1 .. 255.
#define DAP_JTAG_DEV_CNT        8               ///< Maximum number of JTAG devices on scan chain

/// Default communication mode on the Debug Access Port.
/// Used for the command \ref DAP_Connect when Port Default mode is selected.
#define DAP_DEFAULT_PORT        1               ///< Default JTAG/SWJ Port Mode: 1 = SWD, 2 = JTAG.

/// Default communication speed on the Debug Access Port for SWD and JTAG mode.
/// Used to initialize the default SWD/JTAG clock frequency.
/// The command \ref DAP_SWJ_Clock can be used to overwrite this default setting.
#define DAP_DEFAULT_SWJ_CLOCK   1000000         ///< Default SWD/JTAG clock frequency in Hz.
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

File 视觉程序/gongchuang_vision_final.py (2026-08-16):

import os
import sys
import serial
import cv2
import numpy as np
import time 
import threading
from collections import defaultdict
from pyzbar.pyzbar import decode, ZBarSymbol
cv2.setUseOptimized(True)
cv2.setNumThreads(8)
A = ['1','3','2','+','3','1','2']   # 用于存储二维码数据
#A=[]
C_1 = None  
C_2 = None  
C_1_loop2 = None
C_2_loop2 = None
INDEX = 0
INDEX1 = 0
INDEX2 = 0
INDEX_loop2 = 0
INDEX1_loop2 = 0
INDEX2_loop2 = 0
cap=None
cap2=None

# 固定三工位物料区使用同一组 h/i 指令执行两轮。
# 0=二维码 A1/A2/A3，1=二维码 A4/A5/A6，2=两轮已完成。
sangeyuanxin_dangqian_lunci = 0
SANGEYUANXIN_ZONG_LUNCI = 2


def ensure_video2_camera():  # 复用上摄像头
    global cap, cap2

    candidates = []
    for camera in (cap, cap2):
        if camera is None or any(camera is existing for existing in candidates):
            continue
        try:
            if camera.isOpened():
                candidates.append(camera)
        except (cv2.error, AttributeError, TypeError):
            continue

    if candidates:
        selected = candidates[0]
        for duplicate in candidates[1:]:
            try:
                duplicate.release()
            except (cv2.error, AttributeError, TypeError):
                pass
        cap = selected
        cap2 = selected
        return selected

    stale_objects = []
    for camera in (cap, cap2):
        if camera is None or any(camera is existing for existing in stale_objects):
            continue
        stale_objects.append(camera)
        try:
            camera.release()
        except (cv2.error, AttributeError, TypeError):
            pass
    cap = None
    cap2 = None

    camera = cv2.VideoCapture("/dev/video2", cv2.CAP_V4L2)
    if camera is None or not camera.isOpened():
        if camera is not None:
            try:
                camera.release()
            except (cv2.error, AttributeError, TypeError):
                pass
        print("摄像头初始化失败")
        return None

    cap = camera
    cap2 = camera
    print("上摄像头已打开")
    return camera


def release_video2_camera():  # 释放上摄像头
    global cap, cap2
    released = []
    for camera in (cap, cap2):
        if camera is None or any(camera is existing for existing in released):
            continue
        released.append(camera)
        try:
            camera.release()
        except (cv2.error, AttributeError, TypeError):
            pass
    cap = None
    cap2 = None

roi_params_dingxin=(160,140,320,210)
roi_params = (220,70,200, 140)   # 正下方A3    c1
roi_params1 = (110,290,170,160)  # 左下角A1
roi_params2 = (320, 280, 210,160) # 右下角A2
roi_param_zhuazi=(210,300,220,160)#爪子

# 非转盘物料区参数，格式均为 (x, y, width, height)。
# 现场只需调下面三个ROI；Q1/Q2/Q3分别代表三个固定夹取位置。
SANGEYUANXIN_Q1_ROI = (90, 100, 180, 240)
SANGEYUANXIN_Q2_ROI = (225, 100, 170, 240)
SANGEYUANXIN_Q3_ROI = (360, 100, 170, 240)
SANGEYUANXIN_REGION_STABLE_FRAMES = 3
SANGEYUANXIN_COLOR_MIN_AREA_RATIO = 0.02
SANGEYUANXIN_COLOR_DOMINANCE_RATIO = 1.15
SANGEYUANXIN_TOTAL_TIMEOUT = 8.0

# 成品区转盘 Code 128 参数。条码1/2/3就是固定的第一/第二/第三夹取目标，
# 与二维码数组A和颜色映射完全独立。
TIAOXINGMA_VALID_CODES = frozenset(("1", "2", "3"))
TIAOXINGMA_FRAME_WIDTH = 640
TIAOXINGMA_FRAME_HEIGHT = 480
TIAOXINGMA_DINGBIAO_ROI = (120, 80, 400, 217)
TIAOXINGMA_BIANHUA_ROI = (220, 80, 200, 200)
TIAOXINGMA_WEIZHI23_ROI = (160, 270, 300, 200)
TIAOXINGMA_DINGBIAO_DX = 0
TIAOXINGMA_DINGBIAO_DY = 0
TIAOXINGMA_DINGBIAO_STABLE_FRAMES = 30
TIAOXINGMA_DINGBIAO_HISTORY = 15
TIAOXINGMA_BIANHUA_STABLE_FRAMES = 15
TIAOXINGMA_BIANHUA_HISTORY = 15
TIAOXINGMA_XUANZE_STABLE_FRAMES = 30
TIAOXINGMA_XUANZE_HISTORY = 15
TIAOXINGMA_BUJU_STABLE_FRAMES = 3
TIAOXINGMA_MAX_PIXEL_MOVE = 10.0
TIAOXINGMA_CODE_CONFIDENCE = 0.7
TIAOXINGMA_TIMEOUT_SECONDS = 8.0
TIAOXINGMA_FAILURE_PAYLOAD = "000000004"
TIAOXINGMA_CONFIRM_PAYLOAD = "987654321"

# 条码转盘独立状态；禁止复用二维码数组A或颜色转盘的C_1/INDEX等状态。
dingbiao_tiaoma = None
dingbiao_zhongxin = None
bianhua_tiaoma = None
diyici_jiaqu_weizhi = None
dierci_jiaqu_weizhi = None
disanci_jiaqu_weizhi = None
tiaoxingma_fangxiang = None

ser = serial.Serial(
    port='/dev/ttyUSB0',      # 根据你的STM32实际端口进行修改
    baudrate=9600,            # 设置波特率为9600
    bytesize=serial.EIGHTBITS, # 数据位为8
    stopbits=serial.STOPBITS_ONE,  # 停止位为1
    parity=serial.PARITY_NONE,     # 校验位为None 
    timeout=0.1
)

def restart_program():
    print("接收到数字指令0，程序将在20秒后重新启动...")
    time.sleep(20)
    python = sys.executable
    os.execl(python, python, *sys.argv)

def send_data(data):
    array = [ord(char) for char in data]
    while len(array) < 9: 
        array.append(0)
    data_packet = bytes([0xFF] + array[:9] + [0xFE]) 
    ser.write(data_packet)
    print(f"发送: {data_packet}") 

def receive_data():
    if ser.in_waiting > 0:
        data = ser.readline().decode('utf-8').strip()
        return data
    return None

def wait_and_receive_data():
    global A
    start_time = time.time()
    while time.time() - start_time < 1:
        data = receive_data()
        if data and len(data) == 7:
            A = list(data)
            _sangeyuanxin_chongzhi_lunci()
            print(f"接收到的数据: {data}")
            print(f"已存储到数组A: {A}")
            return
    print("等待1秒钟未接收到数据，重新开始...")
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

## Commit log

2026-08-16 初始化上传工创赛资料
    [1.CATPart, 2mm勾爪.stp, 2mm勾爪上.stp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]
2026-08-16 添加资料库 README 说明文档
2026-08-16 Create 视觉程序
2026-08-16 Revise control system and repository overview
    视觉端开发板为 RDK X5，补充 gongchuang_vision.py 说明
2026-08-16 Enhance README with vision program details
    Updated README to include details for both preliminary and final versions of the vision program, including file paths and descriptions. Clarified camera usage and task codes for the competition.
2026-08-16 更新说明文档并新增色环资料
2026-08-16 更新 README：地平线 RDK X5 改为地瓜派RDK X5
2026-08-16 README 补充开源来源说明

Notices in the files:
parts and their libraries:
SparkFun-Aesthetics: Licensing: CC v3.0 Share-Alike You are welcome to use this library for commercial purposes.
